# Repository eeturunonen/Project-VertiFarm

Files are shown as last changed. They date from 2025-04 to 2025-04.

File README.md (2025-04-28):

# **Project-VertiFarm: Vertical Farming System for Home Environment**

## Overview

This vertical farming system is designed for small-scale, home-based plant cultivation using automation and smart control technologies. It integrates environmental sensing, nutrient control, and irrigation management using a combination of Raspberry Pi, ESP32 microcontrollers, and HomeAssistant. The system is energy-efficient, modular, and scalable, housed within a custom-built cabinet with support for hydroponic-style growing.

### System Features

- 🌡️ **Environmental Monitoring**: Real-time temp & humidity feedback.
- 💧 **Smart Irrigation**: Based on tank level and timer schedules.
- ⚗️ **Nutrient Management**: TDS-based auto-dosing of nutrients and pH.
- 💡 **Automated Lighting**: Daily grow cycle via timer-controlled relays.
- 📊 **HomeAssistant Dashboard**: Full control, monitoring, and automation logic.

### Descriptive Insight

The vertical farming system leverages edge computing and IoT frameworks to create a responsive and sustainable growing environment. By modularizing the control using multiple ESP32 nodes, the system remains scalable and failsafe—if one node goes offline, others continue functioning independently.

Using HomeAssistant as the central brain ensures smooth automation logic without needing cloud access, promoting privacy and control. MQTT enables lightweight communication with sensors not directly compatible with ESPHome, like the TDS module, ensuring real-time monitoring and timely responses.

The choice of peristaltic pumps for nutrient and pH delivery provides accurate dosing, crucial for maintaining optimal plant health. Water level sensing using ultrasonic modules prevents dry-run scenarios for pumps, and the submersible pump circulates nutrient-rich water through the channels for plant uptake.

LED grow lights are scheduled to mimic day/night cycles and tuned to plant needs, providing efficient energy use. The cabinet ensures neat housing and minimizes external light interference or heat loss. 

Final Design
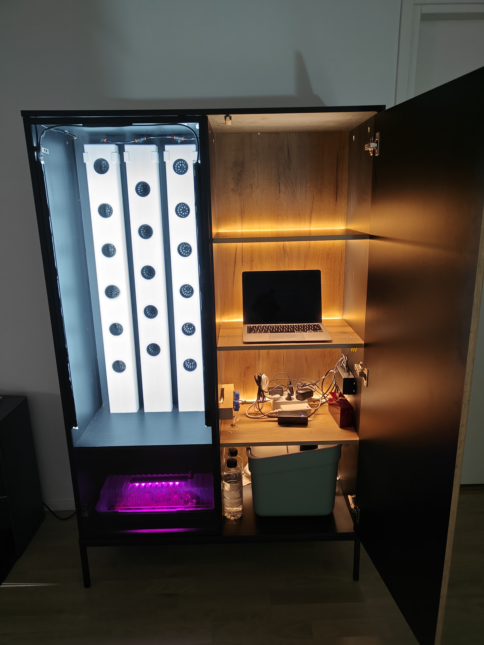
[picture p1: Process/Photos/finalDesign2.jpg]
Final Design
<br><br><br>

## System Architecture

### 🧱 System Node Table

| Node | Role | Components / Modules | Communication |
|---|---|---|---|
| **Raspberry Pi 4** | Central Controller | - Hosts **HomeAssistant Core** | Central Hub |
| **ESP32 Node 1** | Sensor Node | - DHT22 (Temp & Humidity)  <br> - DHT11 (Temp & Humidity) <br> - Ultrasonic Ranger (Water Level) | ESPHome → HomeAssistant |
| **ESP32 Node 2** | Sensor Node | - TDS Sensor (Velleman WPM356) | MQTT → HomeAssistant |
| **ESP32 Node 3** | Actuator Node | - Relay Module (Velleman WPM400) <br> Controls: <ul><li>Main Pump</li><li>Nutrient Pump</li><li>pH Pump</li><li>LED Grow Lights</li></ul> | ESPHome → HomeAssistant |

```mermaid 
flowchart TD
  subgraph ESP32_1["ESP32 Node 1 (ESPHome)"]
    direction LR
      DHT22(["DHT22 Sensor"])
      DHT11(["DHT11 Sensor"])
      USonic(["Ultrasonic Ranger"])
  end
  subgraph ESP32_2["ESP32 Node 2 (MQTT)"]
    direction LR
      TDS(["TDS Sensor"])
  end
  subgraph ESP32_3["ESP32 Node 3 (ESPHome)"]
    Relay(["Relay Module<br>(WPM400)"])
    MainPump(["Main Pump"])
    NutrientPump(["Nutrient Pump"])
    PHPump(["pH Pump"])
    LEDs(["LED Grow Lights"])
  end

  Start(["System Powered On"]) --> Collect(["Collect Sensor Data"])
  MQTT(["MQTT Broker"]) -.-> RPI["Raspberry Pi 4<br>HomeAssistant Core"]
  TDS -.-> MQTT
  DHT22 --> RPI
  DHT11 -.-> RPI
  USonic --> RPI
  RPI ---> Relay
  CheckLight{"Is Light ON/OFF Time?"} -- Yes --> LEDs
  Relay --> MainPump & NutrientPump &  LEDs & PHPump 
  RPI --> LogicRPI(["Automation Engine<br>HomeAssistant Rules"])
  Collect --> RPI
  LogicRPI ---> CheckWater{"Water Level<br>OK?"} & CheckTDS{"TDS Level<br>OK?"} & CheckLight
  CheckTDS -- No --> NutrientPump
  CheckWater -- No --> MainPump

  RPI@{ shape: rect}
    DHT22:::sensor
    DHT11:::sensor
    USonic:::sensor
    TDS:::sensor
    Relay:::relay
    MainPump:::actuator
    NutrientPump:::actuator
    PHPump:::actuator
    LEDs:::actuator
    Start:::logic
    Collect:::logic
    MQTT:::mqtt
    RPI:::sensor
    RPI:::controller
    CheckLight:::condition
    LogicRPI:::logic
    CheckWater:::condition
    CheckTDS:::condition

  classDef mqtt fill:#F1C40F,stroke:#B7950B,color:#000
  classDef relay fill:#FAD7A0,stroke:#E59866,color:#000
  classDef actuator fill:#A9DFBF,stroke:#2ECC71,color:#000
  classDef logic fill:#D2B4DE,stroke:#8E44AD,color:#000
  classDef condition fill:#F7DC6F,stroke:#B7950B,color:#000
  classDef sensor fill:#AEDFF7, stroke:#3B84C0, color:#000
  classDef controller fill:#4A90E2, stroke:#1A3C7B, color:#fff, font-weight:bold
  
  linkStyle 0 stroke:#9B59B6,stroke-width:2px %% System Power to Collect,fill:none
  linkStyle 1 stroke:#2ECC71,stroke-dasharray: 4 3,stroke-width:2px %% MQTT to RPI,fill:none
  linkStyle 2 stroke:#2ECC71,stroke-dasharray: 4 3,stroke-width:2px %% TDS to MQTT,fill:none
  linkStyle 3 stroke:#2ECC71,stroke-dasharray: 4 3,stroke-width:2px %% DHT22 to RPI,fill:none
  linkStyle 4 stroke:#2ECC71,stroke-dasharray: 4 3,stroke-width:2px %% DHT11 to RPI, fill:none,fill:none
  linkStyle 5 stroke:#2ECC71,stroke-dasharray: 4 3,stroke-width:2px %% USonic to RPI,fill:none
  linkStyle 6 stroke:#2ECC71,stroke-dasharray: 4 4,stroke-width:2px %% RPI to Relay,fill:none
  linkStyle 7 stroke:#616161,fill:none,stroke-width:2px %% Condition
  linkStyle 8 stroke:#2ECC71,stroke-dasharray: 4 4,stroke-width:2px %% Relay to Actuators,fill:none
  linkStyle 9 stroke:#2ECC71,stroke-dasharray: 4 4,stroke-width:2px %% Relay to Actuators,fill:none
  linkStyle 10 stroke:#2ECC71,stroke-dasharray: 4 4,stroke-width:2px %% Relay to Actuators,fill:none
  linkStyle 11 stroke:#2ECC71,stroke-dasharray: 4 4,stroke-width:2px %% Relay to Actuators,fill:none
  linkStyle 12 stroke:#9B59B6,stroke-width:2px %% RPI to Automation,fill:none
  linkStyle 13 stroke:#9B59B6,stroke-width:2px %% Collect to RPI, fill:none,fill:none
  linkStyle 14 stroke:#9B59B6,stroke-width:2px %% Automation to Condition,fill:none
  linkStyle 15 stroke:#9B59B6,stroke-width:2px %% Automation to Condition,fill:none
  linkStyle 16 stroke:#9B59B6,stroke-width:2px %% Automation to Condition,fill:none
  linkStyle 17 stroke:#616161,fill:none,stroke-width:2px %% Condition
  linkStyle 18 stroke:#616161,fill:none,stroke-width:2px %% Condition
```

### Data Flow Summary

- **Sensor Data**:
  - Environmental data (temperature, humidity, water level) is collected via ESPHome and pushed to HomeAssistant in real-time.
  - TDS sensor data is transmitted over **MQTT** to HomeAssistant for nutrient level monitoring.

- **Device Control**:
  - HomeAssistant issues control signals to the actuator ESP32 via ESPHome to manage:
    - Water flow (main submersible pump)
    - Nutrient dosing (peristaltic pump)
    - pH- dosing (peristaltic pump)
    - Lighting (LED grow lights)

- **Automation Logic**:
  - Resides in HomeAssistant, which responds to sensor inputs to trigger actions (e.g., refill water, dose nutrients, adjust lighting schedules). <br><br><br>

## Technologies and Components Used

- **Raspberry Pi 4**: Hosts HomeAssistant for centralized automation and monitoring.
- **ESP32-C6-DevKitC-1**: Handles sensor data and relay control.
- **ESPHome**: Used for seamless integration of ESP32 nodes with HomeAssistant.
- **MQTT**: For transmitting TDS sensor data (non-ESPHome compatible).
- **Custom 3D-Printed Components**: Mechanical support for mounting and water channels.

### Sensors & Modules

| Component | Function | Interface |
|---|---|---|
| **Waveshare DHT22 & DHT11** | Temperature and humidity monitoring | ESPHome (ESP32) |
| **Waveshare Ultrasonic Ranger** | Water level detection in tank | ESPHome (ESP32) |
| **Velleman WPM356 (TDS Sensor)** | Measures total dissolved solids in water | MQTT (ESP32) |
| **Velleman WPM400 (Relay Module)** | Controls pumps and lighting | ESPHome (ESP32) |

### Actuators

| Device | Purpose | Power Source  |
|---|---|---|
| **SEAFLO 16LPM 12V Submersible Pump** | Main water circulation | 12V supply |
| **VMA447 Mini Peristaltic Pumps (2x)** | Nutrient and pH delivery | 6V supply |
| **NelsonGarden LED Plant Lights (2x)** | Plant growth illumination  | 24V supply |

### Power Supplies

- **5V DC** – ESP32 devices
- **6V DC** – Peristaltic pumps
- **12V DC** – Submersible water pump
- **24V DC** – LED grow lights

Each power supply is selected based on device voltage and current requirements, routed through the relay module for automated switching.

### Additional Components

- **Water Tank**: 25L capacity for hydroponic reservoir.
- **Nutrient & pH Tanks**: 1L each for solution control.
- **Hosing & Couplings**: Water distribution channels.
- **Cabinet Housing**: Custom-designed, houses entire setup.
- **Water Channels**: Supports vertical growth and drainage.

## Future Improvements

- Integration with cloud services for remote access
- Addition of camera module for plant health monitoring
- Automated refill system for water/nutrient tanks
- Voice assistant integration for hands-free control

## License

This documentation and system design are open for personal and educational use.

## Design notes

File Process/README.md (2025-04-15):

# **Vertical Farming System Deployment Processs**

This document outlines the full deployment process for building and setting up a home-based Vertical Farming System. The project includes component selection, system integration with HomeAssistant via Raspberry Pi, 3D modeling of custom parts, coding, testing, and final customization.

---

## Table of Contents

1. [System Overview](#system-overview)
2. [Component Selection](#component-selection)
3. [Building the System](#building-the-system)
4. [3D Modeling Custom Parts](#3d-modeling-custom-parts)
5. [Setting Up HomeAssistant on Raspberry Pi](#setting-up-homeassistant-on-raspberry-pi)
6. [Connecting Sensors via ESPHome](#connecting-sensors-via-esphome)
7. [Coding and Automation](#coding-and-automation)
8. [Testing and Calibration](#testing-and-calibration)
9. [Jointing and Assembly](#jointing-and-assembly)
10. [Customizing and Final Adjustments](#customizing-and-final-adjustments)
11. [Troubleshooting](#troubleshooting)
12. [Future Improvements](#future-improvements)

---

## 1. System Overview

This project creates a smart vertical farming solution for indoor environments, automating plant care through sensors, automation rules, and a centralized dashboard using HomeAssistant.

---

## 2. Component Selection

### Required Electronics
- Raspberry Pi 4 (4GB or higher)
- MicroSD Card (32GB+)
- ESP32 boards
- DHT22/DHT11 (Temp & Humidity Sensor)
- Ultrasonic Sensor (Monitor Water level)
- Water Pump
- Nutrient & pH Pump
- Grow Lights (LED-based)
- Relay Modules
- Power Supply (5V, 6V, 12V, 24V)
- Jumper Wires, Breadboard or PCBs

### Mechanical & 3D Printed Components
- Platform for plant growing (Used ventilation duct in this prototype)
- Frame for the system (Cabinet in this prototype)
- Water reservoir
- Tubing for irrigation
- 3D printed brackets/holders/mounts

## 3. Setting Up HomeAssistant on Raspberry Pi

1. Flash HomeAssistant OS to SD card using Raspberry Pi Imager.
2. Insert SD card into Raspberry Pi and boot.
3. Follow setup via `http://homeassistant.local:8123`.
4. Update system and install required integrations.

## 4. Building the System

1. Assemble the frame for vertical farming.
2. Install grow lights and irrigation system.
3. Connect water pump to hosing and reservoir.
4. Set up planters and ensure drainage and water flow.

## 5. 3D Modeling Custom Parts

As noticed quite early stage of the project, not all parts are accessible from shops so I had to make needed parts.

### 3D modeling
Used CAD software (Fusion 360 and AutoCAD) to design:
- Plant holders to adjust plant angle in the platform.
- Pipe covers to hold water hosing in place.

Export STL/STEP files and print using PLA/ABS. [See 3D print files](/Project-VertiFarm/Process/3D_Prints)<br><br>
!! Note PLA might not be the best option due it's water resistance!!

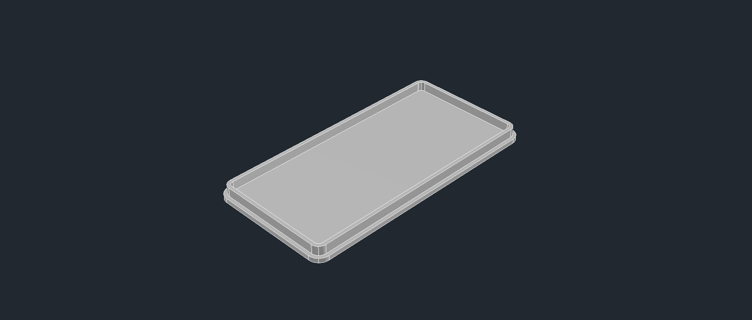
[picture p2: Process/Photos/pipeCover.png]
Pipe Cover

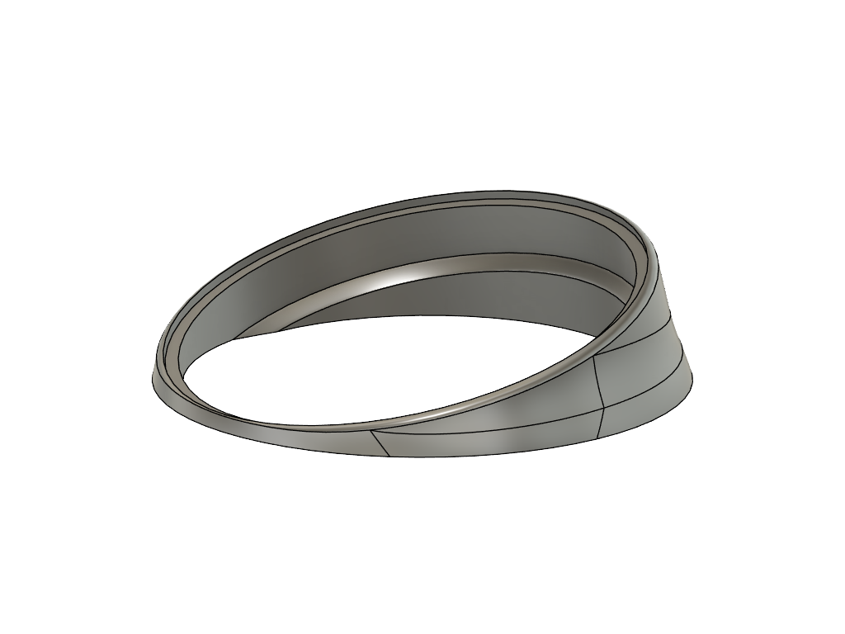
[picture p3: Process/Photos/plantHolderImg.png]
Plant Holder


### Customized parts
1. For water pump I had to create small modifications:
    - Heat the hosing connection point slightly larger to fit pneumatic adapter.
    - Glue the adapter in place with super glue/epoxy to ensure strong joing. Alternatively you can create threads and use the adapter as a "bolt".

    Water Pump modification
    Water Pump modification

2. For plant platform I used ventilation ducts to channel water flow. This needed some adjustments as drilling holes for plant pots.

    Ventilation ducts, planting platform
    Installed platform in the design

## 6. Connecting Sensors

### MQTT

I decided to put TDS sensoring in own module to transmit data using MQTT protocol. This required C/C++ coding and HomeAssistant configurations.

1. Set up MQTT Broker to HomeAssistant.
2. Create C/C++ code for ESP32 to send client data.
    - Flash firmware to ESP32.
    - Ensure the connection variables are set correclty between broker and client.
3. Once the connection is established, you should have YAML file for MQTT in your HomeAssistant.
    - Apply HomeAssistant configures to MQTT YAML file.

```yaml
mqtthomeassistant:
# Loads default set of integrations. Do not remove.
default_config:

# Load frontend themes from the themes folder
frontend:
themes: !include_dir_merge_named themes

automation: !include automations.yaml
script: !include scripts.yaml
scene: !include scenes.yaml
mqtt: !include mqtt.yaml
```

### ESPHome

Since I'm using ESP32-C6-DevKitC-1 boards, ESPHome does not support seamless integration. To overcome this, I utilized Docker to create configuration YAML
files and then flashed the firmware to the board. After first flash, ESPHome integration works well and modifications in configurations can be made through ESPHome.

1. Create YAML configuration file utilizing Docker.
2. Flash firmware to ESP32.
3. Create YAML configurations for each sensor/actuator.
4. Apply sensors to the system.

Encapsulated ESP32 units

An example of YAML configuration:

```yaml
esphome:
  name: sensors
  friendly_name: Sensors

esp32:
  board: esp32-c6-devkitc-1
  framework:
    type: esp-idf

# Enable logging
logger:

# Enable Home Assistant API
api:
  encryption:
    key: !secret sensor_apikey

ota:
  - platform: esphome
    password: somepassword

wifi:
  ssid: !secret wifi_ssid
  password: !secret wifi_password

  # Enable fallback hotspot (captive portal) in case wifi connection fails
  ap:
    ssid: "Sensors Fallback Hotspot"
    password: somepassword

captive_portal:

# Sensors
sensor:
  # 1 Temperature and humidity sensor
  - platform: dht
    model: dht22
    pin: GPIO0
    update_interval: 10s
    temperature:
      name: "DHT22 Temperature"
      id: "Temperature1"
      unit_of_measurement: "°C"
      icon: "mdi:temperature-celcius"
      state_class: "measurement"
      accuracy_decimals: 1

    humidity:
      name: "Humidity"
      id: "Humidity1"
      unit_of_measurement: "%"
      state_class: measurement
      accuracy_decimals: 1

    ...
```

## 7. Coding and Automation

- Used HomeAssistant automations to trigger:
    - Lights based on time.
    - Pumping water at regular intervals.
    - Pump nutrients and pH- based on sensored water data (TDS).
    
- Created C/C++ code for ESP32 to transmit TDS data including followed specifications:
    - Connects to WiFi.
    - Handshake connection with MQTT.
    - Send client data via MQTT.
    - Take ADC readings from TDS sensor.
    - Apply calibration for ADC raw data.

## 8. Testing and Calibration

In progress...

## 9. Jointing and Assembly

In progress...

## 10. Customizing and Final Adjustments

In progress...

## 11. Troubleshooting

In progress...

## 10. Future Improvements

In progress...

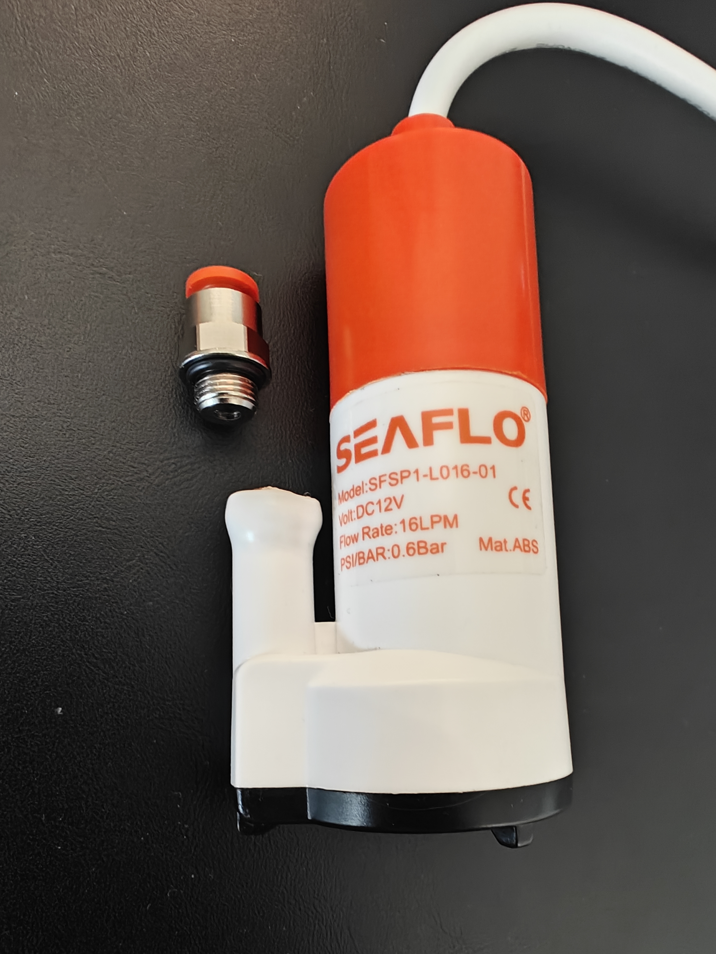
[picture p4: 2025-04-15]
Process/Photos/pumpAdapter1.jpg

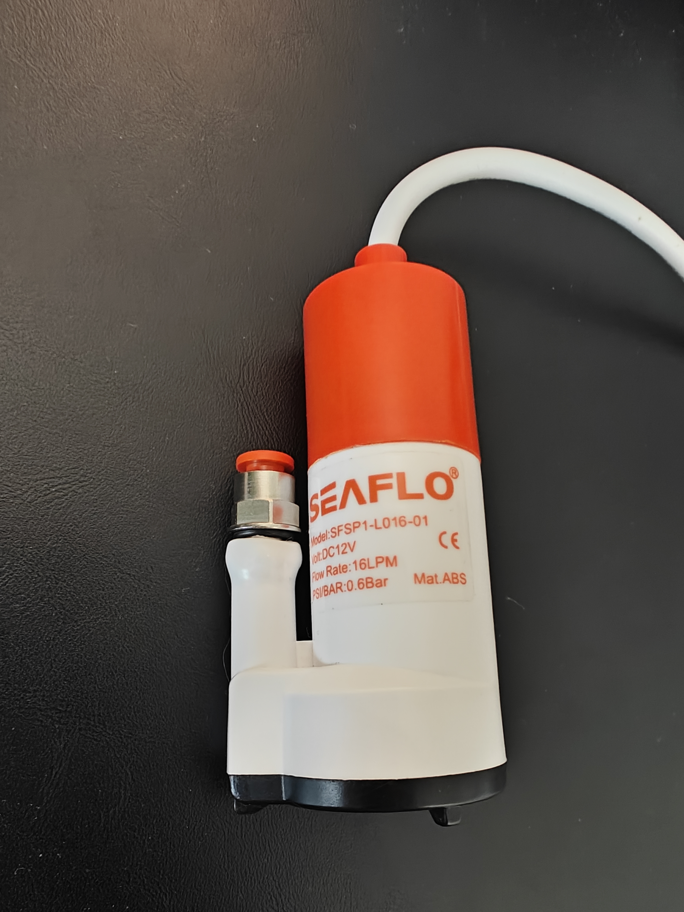
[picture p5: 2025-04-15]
Process/Photos/pumpAdapter2.jpg

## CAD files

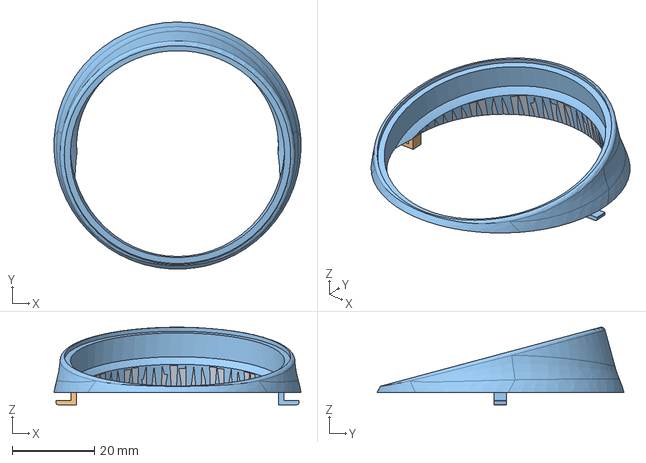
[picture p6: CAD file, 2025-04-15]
Process/3D_Prints/plantHolder.step
60.0 x 60.0 x 18.8 mm

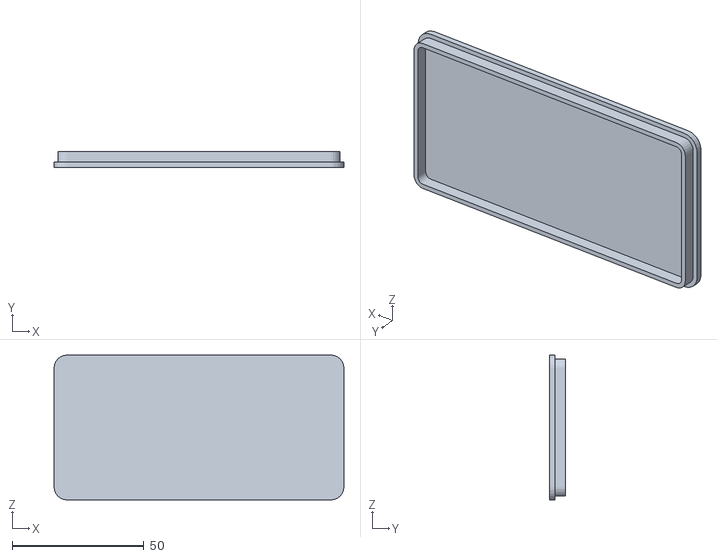
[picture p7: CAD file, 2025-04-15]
Process/3D_Prints/pipeCover.stl
110.0 x 6.00 x 55.0

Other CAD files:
Process/3D_Prints/plantHolder.stl

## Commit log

2025-04-15 Documentation for process. Added photos. Process.md unfinished
    [pipeCover.stl, plantHolder.step]
2025-04-15 Updated plantHolderImg
    [Plant Holder.stl]
2025-04-15 Update stl files
    [Plant Holder.stl, plantHolder.stl]
